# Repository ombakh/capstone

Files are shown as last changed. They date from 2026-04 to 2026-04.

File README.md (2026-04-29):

# Capstone

Browser-based robot control app with directional controls, backend command routing,
Pi telemetry, dual Pi camera streaming, backend-managed session recording, and
ESP32 serial ESC control.

Complete robot guide: [docs/complete-robot.md](./docs/complete-robot.md)
WebRTC video path: [docs/webrtc-video-first-pass.md](./docs/webrtc-video-first-pass.md)
ESP32 serial ESC control: [docs/esp32-serial-esc-control.md](./docs/esp32-serial-esc-control.md)

## Complete Robot Setup

The completed robot baseline in this repo is:

- PC: runs the backend and serves the web app
- Raspberry Pi 5: runs `pi/gateway.py` for controls, telemetry, LiDAR, and
  robot-side status
- WebRTC publisher: runs `pi/webrtc_publisher.py` for low-latency front/back
  camera video
- Web app: shows the two Pi camera feeds, renders LiDAR, exposes arm/disarm,
  and sends arrow-key drive commands
- ESP32: receives serial commands from the Pi and generates hardware-timed
  left/right ESC pulses with a neutral watchdog

Echo mode remains available for bench testing the command path before motors are
armed.

## Project Layout

- `backend/`: realtime gateway for Pi connections and UI commands
- `web/`: static frontend app (`index.html`, `styles.css`, `app.js`)
- `pi/`: Raspberry Pi gateway (`gateway.py`)
- `esp/`: ESP32 serial-controlled ESC firmware
- `docs/`: architecture and protocol notes
- `chasis/`: STL chassis model

## Technical Description: Complete Robot Stack

This section describes the robot stack this repository is built to run.

### Onboard Hardware

- Raspberry Pi 5:
  primary onboard computer that runs the edge gateway, owns the sensors, and
  connects back to the control backend over LAN or Tailscale.
- ESP32 motor controller:
  connected to the Pi over USB serial and responsible for hardware-timed
  left/right ESC signal pulses. The default ESP32 GPIO mapping is `GPIO18` for
  the left ESC and `GPIO19` for the right ESC.
- Two ESC signal leads:
  connected to the ESP32 signal outputs, with a shared signal ground between
  the Pi, ESP32, and ESCs. The checked-in PlatformIO config targets
  bidirectional ESCs with centered neutral.
- Two Raspberry Pi NOIR camera modules:
  attached to the Pi camera connectors and treated as the front and back robot
  cameras. The current default mapping is camera index `0` for the front feed and
  camera index `1` for the back feed.
- LiDAR sensor:
  connected over USB serial and streamed by the Pi as `lidar.scan` events for
  the frontend map view.

### Onboard Software

- `pi/gateway.py`:
  the main robot-side process. It connects to the backend as the robot device,
  publishes Pi temperature, camera status, live camera frames, and LiDAR data,
  and drives motors in one of three modes: terminal echo, ESP32 serial ESC
  control, or legacy direct Pi GPIO ESC control.
- Raspberry Pi camera stack:
  the preferred live-camera path uses `rpicam-vid` or `libcamera-vid`; OpenCV is
  only a fallback when those tools are unavailable.
- Python dependencies:
  the Pi gateway depends on `websockets`, `pyserial`, and
  `rplidar-roboticia`, with `python3-opencv` optional for the fallback camera
  path.
- Serial links:
  the Pi can maintain one USB serial path to the LiDAR and another to the ESP32,
  depending on whether the robot is in echo-only mode or using the ESP32 motor
  controller.

### Low-Level Control Status

- The primary robot control path is ESP32 serial ESC control:
  web UI -> backend -> Pi gateway -> ESP32 serial -> left/right ESC signal pulses.
- The web UI does not drive live motors immediately. It must receive
  `motor.status` from the Pi, you must arm the ESCs explicitly, and held arrow
  keys are refreshed from the browser while the ESP32 applies its watchdog
  timeout and neutral fallback.
- The legacy direct Pi ESC path still exists as `PI_MOTOR_DRIVER=esc`, but the
  preferred motor path is `PI_MOTOR_DRIVER=esp`.

### Off-Robot Infrastructure

- Backend server:
  runs on a separate PC and acts as the command broker, WebRTC signaling relay,
  recording coordinator, and realtime fan-out service for UI clients and the Pi.
- Web frontend:
  served from the PC, shows the robot camera feeds and LiDAR view, and
  sends drive commands to the robot. It can also start/stop backend-managed
  recording sessions, pause/resume them mid-run, and download the finished
  fixed-layout MP4 once rendering completes.
- Network dependency:
  the Pi must be able to reach the backend on port `3000`; the documented setup
  uses either the local network or Tailscale.

### Practical Summary

The robot is a Raspberry Pi 5 with two NOIR cameras, USB LiDAR, an ESP32 serial
ESC controller, two ESCs, and the chassis model in this repo. The normal
development topology keeps backend/web hosting on the PC; move that onto the Pi
only if the deployment plan changes.

## Requirements

PC:

- `node` and `npm` (`backend/package.json` requires Node `>=18`)
- `python3`
- `make`
- PlatformIO CLI (`pio`) for ESP32 firmware builds/uploads
- macOS Swift command-line toolchain when rendering recording MP4s

Pi:

- `python3`
- `make`
- a Python virtual environment is strongly recommended

## Quick Start: Echo Bench Test

### 1. Start the PC side

```bash
make pc-setup
make pc-start
```

That runs:

- backend on `0.0.0.0:3000`
- web app on `http://127.0.0.1:8080`

### 2. Prepare the Pi Python environment

From the repo root on the Pi:

```bash
python3 -m venv .venv
source .venv/bin/activate
make pi-setup
```

### 3. Connect the Pi to the PC backend

If both devices are on a network that allows peer-to-peer traffic:

```bash
make pi-connect-echo PC_IP=<pc-ip>
```

If you are on campus or guest Wi-Fi, use the PC's Tailscale IP instead of its
local Wi-Fi IP.

`make pi-connect-echo` now carries LiDAR scans over the same backend path by
default. The Makefile leaves the serial device unset unless you pass
`PI_LIDAR_PORT=/dev/ttyUSB1`, so `gateway.py` can apply its motor-driver-specific
default. Disable streaming with `PI_LIDAR_ENABLED=0`.

To isolate LiDAR hardware from the webapp path, stop the Pi gateway and run
this on the Pi:

```bash
make pi-serial-list
make pi-lidar-check
```

If the LiDAR is not on the default serial device, pass the detected port:

```bash
make pi-lidar-check PI_LIDAR_PORT=/dev/ttyUSB0
```

The Pi gateway also logs the detected serial devices and the selected `espPort`
and `lidarPort` at startup. If the ESP32 and LiDAR swap `/dev/ttyUSB*` numbers,
prefer passing the stable `/dev/serial/by-id/...` path shown by
`make pi-serial-list` as `ESP_SERIAL_PORT` or `PI_LIDAR_PORT`.

When LiDAR is enabled and only one USB serial device is detected, the gateway
reserves that device for LiDAR and leaves the ESP motor serial port unassigned
unless `ESP_SERIAL_PORT` is explicitly set. This keeps LiDAR scans working even
when the ESP32/motor controller is not plugged in.

The complete drive target uses those stable paths like this:

```bash
make pi-connect-webrtc-esp PC_IP=192.168.1.25 \
  ESP_SERIAL_PORT=/dev/serial/by-id/<esp32-device> \
  PI_LIDAR_PORT=/dev/serial/by-id/<lidar-device>
```

### 4. Use the web app

Open `http://127.0.0.1:8080` on the PC and press the arrow keys.

If two camera modules are attached to the Pi, the main view and side preview use
camera index `0` as the front feed and camera index `1` as the back feed. The
WebRTC targets publish both feeds over WebRTC; non-WebRTC Pi targets carry
camera frames over the backend WebSocket path.

To verify both camera indexes outside the webapp/WebRTC path, stop the Pi
service and run:

```bash
make pi-camera-check
```

The check captures each camera once, then runs a short simultaneous
WebRTC-style stream probe. If the still captures pass but the simultaneous
stream fails, check camera power/cables or lower the WebRTC resolution/FPS. If
the reported camera indexes are reversed or different, override them with
`WEBRTC_CAMERA_FRONT_INDEX` and `WEBRTC_CAMERA_BACK_INDEX` in the service.

Expected Pi output:

```text
Motor command [echo-only] id=... drive direction=forward speed=0.15 durationMs=3000
Motor command [echo-only] id=... stop
```

## Quick Start: Complete Robot Drive Mode

This is the normal live-driving mode for the complete robot. The Raspberry Pi
forwards commands over serial, the ESP32 generates ESC signal pulses, LiDAR
streams through the gateway, and both cameras publish over WebRTC.

### 1. Flash the ESP32 firmware

From the repo root on the PC:

```bash
pio run -d esp
pio run -d esp -t upload
```

The firmware emits `motor.status` JSON at `115200` baud.

### 2. Install the Pi Python dependencies

From the repo root on the Pi:

```bash
python3 -m venv .venv
source .venv/bin/activate
make pi-setup
```

`pyserial` is required for the Pi-to-ESP32 link.

### 3. Wire the ESC receiver leads to the ESP32

Default signal pins:

- Left ESC signal -> ESP32 GPIO `18`
- Right ESC signal -> ESP32 GPIO `19`
- ESC signal grounds -> ESP32 ground
- Pi ground -> ESP32 ground
- Pi USB -> ESP32 USB serial

Power rules:

- Do not power the motors from the Pi or ESP32.
- Power each ESC from the robot battery or motor power bus.
- The Pi, ESP32, and both ESCs must share signal ground.
- Do not tie multiple ESC BEC 5V outputs together.
- Do not backfeed ESC voltage into Pi or ESP32 GPIO.

### 4. Start ESP32 ESC mode and WebRTC video on the Pi

If the Pi is connecting to a PC-hosted backend:

```bash
make pi-connect-webrtc-esp PC_IP=<pc-ip>
```

When possible, pass stable serial paths from `make pi-serial-list`:

```bash
make pi-connect-webrtc-esp PC_IP=<pc-ip> \
  ESP_SERIAL_PORT=/dev/serial/by-id/<esp32-device> \
  PI_LIDAR_PORT=/dev/serial/by-id/<lidar-device>
```

### 5. Arm and drive from the web app

- Open the web app on the PC.
- Wait for the motor panel to show the ESP driver as available.
- Click `Arm Motors`.
- Wait for the panel to change from `ARMING` to `ARMED`.
- Use the arrow keys.

The ESP32 keeps both ESCs at neutral on startup, disarm, stop, and watchdog
timeout. While a key is held, the web app refreshes the `drive` command; if
those refreshes stop, the ESP32 returns both ESCs to neutral automatically.

## Recording Mode

Backend recording captures LiDAR scans and backend-carried JPEG camera frames.
The live WebRTC media path is peer-to-peer, so use the non-WebRTC Pi target when
you need the rendered MP4 to include both camera feeds:

```bash
make pi-connect-esp PC_IP=<pc-ip> \
  ESP_SERIAL_PORT=/dev/serial/by-id/<esp32-device> \
  PI_LIDAR_PORT=/dev/serial/by-id/<lidar-device>
```

Then open:

```text
http://127.0.0.1:8080?deviceId=pi-01&webrtc=0
```

Start, pause/resume, and stop recording from the web UI. The backend renders the
finished session into an MP4 using [backend/scripts/render_recording.swift](./backend/scripts/render_recording.swift).

## ESP32 ESC Wiring

The ESP32 ESC path assumes ESCs that accept standard RC servo-style control
pulses, not DShot-only ESCs.

Default wiring:

- Left ESC signal -> ESP32 GPIO `18`
- Right ESC signal -> ESP32 GPIO `19`
- ESC signal grounds -> ESP32 ground
- Pi ground -> ESP32 ground
- ESC main battery leads -> robot battery / motor power distribution
- Brushless motor phase wires -> ESC motor outputs

If your drivetrain is mounted so one side spins the opposite way for the same
throttle command, compile the firmware with `ESC_LEFT_INVERTED=1` or
`ESC_RIGHT_INVERTED=1`, or swap motor phase wires where appropriate.

The checked-in [esp/platformio.ini](./esp/platformio.ini) config is tuned for
the complete robot's bidirectional ESCs:

- `ESC_BIDIRECTIONAL=1`
- `ESC_ARM_PULSE_US=1500`
- `ESC_NEUTRAL_PULSE_US=1500`
- `ESC_FORWARD_MIN_PULSE_US=1560`
- `ESC_FORWARD_MAX_PULSE_US=1900`
- `ESC_REVERSE_MIN_PULSE_US=1440`
- `ESC_REVERSE_MAX_PULSE_US=1100`
- `ESC_MAX_SPEED=0.35f`

The ESP32 arms by holding `ESC_ARM_PULSE_US` for `ESC_ARM_DELAY_MS`, clamps
requested speed to `ESC_MAX_SPEED`, and returns both ESCs to neutral if command
refresh stops for `ESC_WATCHDOG_TIMEOUT_MS`.

Detailed setup: [docs/esp32-serial-esc-control.md](./docs/esp32-serial-esc-control.md)

## Network Notes

- The Pi must be able to reach the PC backend on port `3000`.
- Many campus, guest, and enterprise Wi-Fi networks block device-to-device traffic.
- If `curl http://<pc-ip>:3000/health` hangs from the Pi, use Tailscale or a different network.

## Useful Commands

- `make serve`: serve `web/` on `WEB_HOST:PORT`
- `make run`: run backend and web app together with default local settings
- `make check`: run `node --check` on `web/app.js`
- `make backend-install`: install backend dependencies
- `make backend-dev`: run backend in watch mode
- `make backend-start`: run backend without watch mode
- `make pc-setup`: install PC-side backend dependencies
- `make pc-backend`: run the backend on the PC
- `make pc-web`: serve the web app on the PC
- `make pc-start`: run backend and web app on the PC
- `make pi-install`: install Raspberry Pi gateway dependencies
- `make pi-setup`: install Raspberry Pi gateway dependencies
- `make pi-run`: run the Pi gateway with its default settings
- `make pi-run-echo`: run the Pi gateway in local echo-only mode
- `make pi-run-esp`: run the Pi gateway with ESP32 serial ESC control
- `make pi-run-esc`: run the legacy direct Pi GPIO ESC path
- `make pi-connect-echo PC_IP=<ip>`: connect the Pi echo gateway to the PC backend
- `make pi-connect-esp PC_IP=<ip>`: connect the Pi ESP32 ESC gateway to the PC backend
- `make pi-connect-esc PC_IP=<ip>`: connect the legacy direct Pi GPIO ESC gateway to the PC backend
- `make pi-connect-webrtc-echo PC_IP=<ip>`: connect echo controls and publish WebRTC video
- `make pi-connect-webrtc-esp PC_IP=<ip>`: connect ESP32 ESC controls and publish WebRTC video
- `make pi-connect-webrtc-esc PC_IP=<ip>`: connect legacy direct Pi GPIO ESC controls and publish WebRTC video
- `CAMERA_STREAM_HZ`, `CAMERA_FRAME_WIDTH`, `CAMERA_FRAME_HEIGHT`, `CAMERA_JPEG_QUALITY`: tune Pi camera streaming
- `WEBRTC_CAMERA_NAMES=front,back`, `WEBRTC_CAMERA_FRONT_INDEX`, `WEBRTC_CAMERA_BACK_INDEX`, `WEBRTC_CAMERA_WIDTH`, `WEBRTC_CAMERA_HEIGHT`, `WEBRTC_CAMERA_FPS`: tune WebRTC camera streaming
- `WEBRTC_CAMERA_FRONT_WIDTH`, `WEBRTC_CAMERA_FRONT_HEIGHT`, `WEBRTC_CAMERA_FRONT_FPS`, `WEBRTC_CAMERA_BACK_WIDTH`, `WEBRTC_CAMERA_BACK_HEIGHT`, `WEBRTC_CAMERA_BACK_FPS`: override per-camera WebRTC profiles
- `PI_LIDAR_PORT=/dev/ttyUSB1`: override the LiDAR serial port when the gateway default is wrong
- `PI_MOTOR_DRIVER=esp`, `ESP_SERIAL_PORT`, `ESP_BAUD`: use the ESP32 serial ESC path
- `ESC_*` firmware build flags in `esp/platformio.ini`: tune ESP32 ESC pulses
- `make pi-keys`: send direct arrow-key serial input to an attached ESP32
- `make help`: list available targets

## Additional Docs

- Complete robot guide: [docs/complete-robot.md](./docs/complete-robot.md)
- Pi gateway: [pi/README.md](./pi/README.md)
- ESP32 firmware: [esp/README.md](./esp/README.md)
- ESP32 ESC setup: [docs/esp32-serial-esc-control.md](./docs/esp32-serial-esc-control.md)
- WebRTC video path: [docs/webrtc-video-first-pass.md](./docs/webrtc-video-first-pass.md)
- Backend API and WebSocket protocol: [backend/README.md](./backend/README.md)
- End-to-end architecture: [docs/edge-system-base.md](./docs/edge-system-base.md)

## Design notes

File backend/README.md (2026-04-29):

# Backend Gateway

Realtime gateway between the complete robot's Raspberry Pi gateway, WebRTC
publisher, and web frontend.

This service is the command broker for the project:

- UI clients connect as `role=ui`
- Pi gateways connect as `role=pi`
- UI commands are validated, queued if needed, and forwarded to the target Pi
- Pi events and acknowledgements are broadcast back to connected UI clients
- WebRTC signaling is relayed between the browser viewer and Pi publisher
- The backend can record LiDAR scans and backend-carried camera frames into
  session folders and render the finished session as a downloadable MP4

## Run

From the repo root:

```bash
make backend-install
make backend-start
```

Or directly from `backend/`:

```bash
cd backend
npm install
npm run dev
```

Server defaults to `http://127.0.0.1:3000` locally and listens on `0.0.0.0`
when started through the root `Makefile`.

## Environment

- `BACKEND_HOST` default: `0.0.0.0`
- `BACKEND_PORT` default: `3000`
- `BACKEND_CORS_ORIGINS` default: `*`
- `PI_DEVICE_TOKEN` optional shared token for Pi auth
- `EVENT_HISTORY_LIMIT` default: `300`
- `COMMAND_QUEUE_LIMIT` default: `100`
- `BACKEND_RECORDINGS_DIR` default: `<backend cwd>/recordings`
- `RECORDINGS_HISTORY_LIMIT` default: `25`
- `RECORDING_VIDEO_WIDTH` default: `1280`
- `RECORDING_VIDEO_HEIGHT` default: `720`
- `RECORDING_VIDEO_FPS` default: `12`
- `RECORDING_RENDERER_SCRIPT` default: `<backend cwd>/scripts/render_recording.swift`

## Health Check

```bash
curl http://127.0.0.1:3000/health
```

Expected response shape:

```json
{
  "ok": true,
  "uptimeSeconds": 12,
  "connectedUiClients": 1,
  "connectedPiClients": 1,
  "connectedWebRtcPiClients": 1,
  "connectedWebRtcViewerClients": 1
}
```

When using a PC-hosted backend with a Pi on another device, verify that the Pi
can reach this endpoint before debugging the WebSocket path.

## HTTP API

- `GET /health`: liveness + connection counts
- `GET /api/state`: latest in-memory snapshot
- `POST /api/pi/event`: ingest Pi event payload
- `POST /api/ui/command`: send command to a Pi device
- `POST /api/ui/drive`: validated drive command helper endpoint
- `POST /api/recordings/start`: begin backend-managed recording for a Pi device
- `POST /api/recordings/pause`: pause or resume an active recording
- `POST /api/recordings/stop`: stop and render an active recording
- `GET /api/recordings/:recordingId/download`: download a finished recording MP4

### `POST /api/pi/event` payload

```json
{
  "deviceId": "pi-01",
  "eventType": "telemetry",
  "payload": {
    "battery": 89,
    "heading": 42
  }
}
```

### `POST /api/ui/command` payload

```json
{
  "deviceId": "pi-01",
  "command": "drive",
  "params": {
    "direction": "forward",
    "speed": 0.6
  }
}
```

### `POST /api/ui/drive` payload

```json
{
  "deviceId": "pi-01",
  "direction": "forward",
  "speed": 0.6,
  "durationMs": 0
}
```

### `POST /api/recordings/start` payload

```json
{
  "deviceId": "pi-01"
}
```

The backend stores:

- `lidar.ndjson`
- `camera-front.ndjson` / `camera-back.ndjson`
- JPEG frames under `cameras/front/` and `cameras/back/`
- `manifest.json`

When stopped, the backend renders the session into a fixed-layout `.mp4` with a
large LiDAR view and any camera feeds received on the backend WebSocket path.
The web UI keeps the download arrow hidden until that MP4 is ready.
The default renderer is the Swift script in `backend/scripts/`, so the host
running the backend must have the macOS command-line Swift toolchain available.

The low-latency WebRTC media path is peer-to-peer and is not recorded by the
backend. For MP4s with both camera feeds, run the Pi gateway JPEG camera path
and open the browser with `?webrtc=0`.

## WebSocket

Path: `/ws`

- UI connect: `/ws?role=ui`
- Pi connect: `/ws?role=pi&deviceId=pi-01&token=<PI_DEVICE_TOKEN>`

Message types:

- Pi -> backend: `pi:event`, `pi:ack`, `pi:heartbeat`
- Pi -> backend: `pi:camera_frame`
- UI -> backend: `ui:command`
- Backend -> UI: `snapshot`, `pi:event`, `pi:status`, `pi:ack`, `command:accepted`, `command:delivered`, `camera:frame`, `recording:status`, `pi:webrtc-status`
- Backend -> Pi: `ui:command`

WebRTC signaling path: `/webrtc`

- Pi publisher connect: `/webrtc?role=pi&deviceId=pi-01&token=<PI_DEVICE_TOKEN>`
- Browser viewer connect: `/webrtc?role=viewer&deviceId=pi-01`
- Signaling messages: `viewer:ready`, `viewer:profile`, `webrtc:offer`, `webrtc:answer`, `webrtc:ice`
- The backend relays only signaling. WebRTC video media flows peer-to-peer.

See [WebRTC Video Path](../docs/webrtc-video-first-pass.md) for the run flow.

## Common Development Topology

The complete robot development flow is:

- PC runs this backend on port `3000`
- PC serves the web app on port `8080`
- Pi runs `pi/gateway.py`
- Pi runs `pi/webrtc_publisher.py` for low-latency live video when using a
  WebRTC target
- Pi connects to the PC over LAN or Tailscale

If the Pi cannot reach the PC on campus Wi-Fi, use a Tailscale IP or another
network that allows peer-to-peer traffic.

See [Complete Robot Guide](../docs/complete-robot.md) for the full bring-up
sequence.

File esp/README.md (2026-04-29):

# ESP32 ESC Firmware

This PlatformIO project contains the ESP32 firmware for low-level motor signal
generation. The Raspberry Pi sends newline-delimited JSON commands over serial;
the ESP32 owns the ESC PWM outputs for the complete robot.

## What It Does

- Generates hardware-timed 50 Hz RC servo pulses with ESP32 LEDC.
- Drives two ESC signal outputs, defaulting to GPIO `18` left and GPIO `19` right.
- Holds neutral on boot, disarm, stop, and watchdog timeout.
- Requires `arm_motors` before drive commands are accepted.
- Ramps pulse widths toward targets to avoid abrupt throttle changes.
- Publishes `motor.status` JSON lines back to the Pi once per second and on state
  changes.

## Complete Robot Configuration

The firmware source has conservative forward-only compile defaults, but the
checked-in [platformio.ini](./platformio.ini) overrides them for the complete
robot's bidirectional ESCs:

| Setting | Current repo value |
| --- | --- |
| `ESC_BIDIRECTIONAL` | `1` |
| `ESC_ARM_PULSE_US` | `1500` |
| `ESC_NEUTRAL_PULSE_US` | `1500` |
| `ESC_FORWARD_MIN_PULSE_US` | `1560` |
| `ESC_FORWARD_MAX_PULSE_US` | `1900` |
| `ESC_REVERSE_MIN_PULSE_US` | `1440` |
| `ESC_REVERSE_MAX_PULSE_US` | `1100` |
| `ESC_MAX_SPEED` | `0.35f` |

Keep those values synchronized with the ESC calibration verified on the bench.
The checked-in upload and monitor port point at the development USB adapter;
override them from the command line or edit `platformio.ini` if your adapter
enumerates differently.

## Wiring

Default signal wiring:

- Left ESC signal -> ESP32 GPIO `18`
- Right ESC signal -> ESP32 GPIO `19`
- ESC signal grounds -> ESP32 ground
- Raspberry Pi ground -> ESP32 ground
- ESP32 USB -> Raspberry Pi USB for serial

Power each ESC from the robot battery or motor power bus. Do not power motors
from the ESP32 or Raspberry Pi, and do not backfeed ESC BEC outputs into either
board unless you have a deliberate power-distribution plan.

## Build And Upload

From the repo root:

```bash
pio run -d esp
pio run -d esp -t upload
```

Monitor the JSON status stream:

```bash
pio device monitor -d esp -b 115200
```

Bench-test directly from a Mac or Linux host connected to the ESP32:

```bash
python3 esp/serial_motor_test.py --list-ports
python3 esp/serial_motor_test.py --port /dev/cu.usbserial-XXXX
```

Controls:

- `a`: arm
- `d`: disarm
- arrow keys: drive
- space or `s`: stop
- `+` / `-`: adjust speed
- `m`: request status
- `q`: quit

Install `pyserial` first if needed:

```bash
pip install pyserial
```

## Serial Commands

The Pi gateway sends compact JSON lines like:

```json
{"type":"command","id":"123","command":"drive","params":{"direction":"forward","speed":0.15,"durationMs":3000}}
```

Supported commands:

- `motor_status`
- `arm_motors`
- `disarm_motors`
- `drive` with `direction`, `speed`, and `durationMs`
- `stop`

The firmware responds with `ack` lines for non-drive commands and drive errors,
and with `motor.status` lines for frontend safety state.

## Tuning

Compile defaults are defined in [src/main.cpp](./src/main.cpp). Override them
with PlatformIO build flags when needed:

```ini
build_flags =
  -D LEFT_ESC_PIN=18
  -D RIGHT_ESC_PIN=19
  -D ESC_MAX_SPEED=0.15f
  -D ESC_ARM_PULSE_US=1000
  -D ESC_NEUTRAL_PULSE_US=1000
  -D ESC_FORWARD_MIN_PULSE_US=1100
  -D ESC_FORWARD_MAX_PULSE_US=2000
```

For another bidirectional ESC calibration, start from the current repo flags and
adjust the pulse widths:

```ini
build_flags =
  -D ESC_BIDIRECTIONAL=1
  -D ESC_ARM_PULSE_US=1500
  -D ESC_NEUTRAL_PULSE_US=1500
  -D ESC_FORWARD_MIN_PULSE_US=1560
  -D ESC_FORWARD_MAX_PULSE_US=1900
  -D ESC_REVERSE_MIN_PULSE_US=1440
  -D ESC_REVERSE_MAX_PULSE_US=1100
  -D ESC_MAX_SPEED=0.35f
```

Use the lower speed cap until each ESC is calibrated and the drivetrain is
tested on a stand.

If one side of the drivetrain is mechanically mirrored, add
`ESC_LEFT_INVERTED=1` or `ESC_RIGHT_INVERTED=1` instead of changing the browser
direction mapping.

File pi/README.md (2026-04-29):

# Raspberry Pi Robot Gateway

`gateway.py` is the robot-side bridge between the PC backend, onboard sensors,
and the motor controller.

Responsibilities:

- Connect to backend WebSocket as a Pi device (`role=pi`).
- Print incoming drive commands in echo mode for bench testing.
- Forward drive/motor commands to an ESP32 over serial for ESC pulse generation.
- Keep the legacy direct Raspberry Pi GPIO ESC path available for fallback tests.
- Publish motor status, camera status, LiDAR status, temperature, and ESP telemetry.
- Stream live JPEG frames for both configured Pi cameras to the frontend.
- Stream live LiDAR scans (`lidar.scan`) to backend for web rendering.

The WebRTC video path runs as a separate Pi publisher process:
`pi/webrtc_publisher.py`. Use `PI_CAMERA_JPEG_ENABLED=0` on `gateway.py` when
the WebRTC publisher owns the camera. See
[WebRTC Video Path](../docs/webrtc-video-first-pass.md).

## Install

From the repo root on the Pi:

```bash
python3 -m venv .venv
source .venv/bin/activate
make pi-setup
```

The preferred camera path uses `rpicam-vid` or `libcamera-vid`, which are part
of the Raspberry Pi camera stack. OpenCV remains a fallback path when those
commands are unavailable.

Optional for the OpenCV fallback:

```bash
sudo apt-get install -y python3-opencv
```

The preferred motor path uses `pyserial` to talk to the ESP32.

Optional for the legacy direct Pi GPIO ESC fallback:

```bash
sudo apt-get install -y swig build-essential python3-dev liblgpio-dev
python3 -m pip install lgpio
```

## Run

With the virtual environment activated:

```bash
make pi-run
```

For no-hardware testing, run the gateway in terminal echo mode:

```bash
make pi-run-echo
```

For ESP32 serial ESC control:

```bash
make pi-run-esp
```

For legacy direct Raspberry Pi GPIO ESC control:

```bash
make pi-run-esc
```

To connect the Pi to a PC-hosted backend in echo mode:

```bash
make pi-connect-echo PC_IP=<pc-ip>
```

To connect in ESP32 ESC mode:

```bash
make pi-connect-esp PC_IP=<pc-ip>
```

To connect in legacy direct Pi GPIO ESC mode:

```bash
make pi-connect-esc PC_IP=<pc-ip>
```

If the local Wi-Fi blocks device-to-device traffic, use the PC's Tailscale IP.

With two camera modules attached, the web UI can show live Pi feeds through the
WebRTC publisher or through backend-carried JPEG frames, depending on the run
target. The default mapping is camera index `0` for the front feed and camera
index `1` for the back feed. The web settings menu can adjust the JPEG camera
FPS at runtime; WebRTC profiles are set with `WEBRTC_CAMERA_*` environment
variables.

## Complete Robot Run Profiles

Low-latency driving profile:

1. Start the backend and web app on the PC with `make pc-start`.
2. Flash the ESP32 firmware from `esp/`.
3. Wire ESC signal and ground leads to the ESP32, with Pi and ESP32 grounds common.
4. Activate the Pi virtual environment.
5. Run `make pi-serial-list` and prefer stable `/dev/serial/by-id/...` paths.
6. Run `make pi-connect-webrtc-esp PC_IP=<pc-ip-or-tailscale-ip>`.
7. Open the web app, wait for WebRTC, LiDAR, and motor status, click
   `Arm Motors`, then use the arrow keys.

Recording profile:

1. Start the backend and web app on the PC with `make pc-start`.
2. Activate the Pi virtual environment.
3. Run `make pi-connect-esp PC_IP=<pc-ip-or-tailscale-ip>`.
4. Open `http://127.0.0.1:8080?deviceId=pi-01&webrtc=0`.
5. Use the web recording controls to capture LiDAR plus backend-carried JPEG
   camera frames.

Echo bench profile:

1. Start the backend and web app on the PC with `make pc-start`.
2. Activate the Pi virtual environment.
3. Run `make pi-connect-echo PC_IP=<pc-ip-or-tailscale-ip>`.
4. Press the web app arrow keys on the PC.
5. Watch the Pi terminal print the received motor commands.

See the full operating sequence in
[Complete Robot Guide](../docs/complete-robot.md).

## ESP32 Serial ESC Control

This is the complete robot's primary motor path. It assumes ESCs that accept
standard RC servo-style control pulses. DShot-only ESCs are not compatible with
this firmware.

Default wiring:

- Pi USB -> ESP32 USB serial
- Pi ground -> ESP32 ground
- Left ESC signal -> ESP32 GPIO `18`
- Right ESC signal -> ESP32 GPIO `19`
- ESC grounds -> ESP32 ground

Browser, Pi, and ESP32 safety behavior:

1. The ESP32 boots with both ESC outputs held at neutral.
2. The ESP32 publishes `motor.status` JSON over serial.
3. The Pi republishes fresh ESP status to the backend as `motor.status`.
4. The browser keeps the arrow keys disabled until the ESP32 reports
   `readyForDrive=true`.
5. You must click `Arm Motors` in the web UI.
6. The ESP32 holds `ESC_ARM_PULSE_US` for `ESC_ARM_DELAY_MS`.
7. While a key is held, the browser refreshes the `drive` command.
8. If refreshes stop for longer than `ESC_WATCHDOG_TIMEOUT_MS`, the ESP32 forces
   both ESCs back to neutral.
9. If ESP status becomes stale, the Pi marks the motor driver unavailable and
   the browser disables drive.

Detailed setup: [ESP32 Serial ESC Control](../docs/esp32-serial-esc-control.md).

## Legacy Direct Pi ESC Control

This fallback mode assumes ESCs that accept standard RC servo-style control
pulses and uses Raspberry Pi GPIO timing through `lgpio`. The complete robot
uses the ESP32 serial path above; keep this path for comparison or emergency
fallback testing.

Default GPIO wiring:

- Left ESC signal -> `GPIO18` (physical pin `12`)
- Right ESC signal -> `GPIO19` (physical pin `35`)
- ESC grounds -> any Pi ground, for example physical pin `14`, `20`, or `39`

Power and safety rules:

- The Pi and both ESCs must share a common ground.
- Do not power the motors from the Pi.
- Power each ESC from the robot battery or motor power bus.
- Most ESC receiver leads expose `signal`, `5V/BEC`, and `ground`.
  Recommended: connect only `signal` and `ground` to the Pi unless you have a
  deliberate regulator and power-distribution plan.
- Do not tie multiple ESC BEC 5V outputs together.
- Do not feed 5V into a Pi GPIO pin.

Browser and Pi safety behavior:

1. The Pi boots with both ESC outputs held at neutral.
2. The browser requests `motor.status` and keeps the arrow keys disabled until
   the Pi reports the motor driver is ready.
3. You must click `Arm Motors` in the web UI.
4. The Pi holds `ESC_ARM_PULSE_US` for `ESC_ARM_DELAY_SEC`.
5. Only when the Pi reports `ARMED` do arrow keys become live.
6. While a key is held, the browser refreshes the `drive` command.
7. If refreshes stop for longer than `ESC_WATCHDOG_TIMEOUT_MS`, the Pi forces
   both ESCs back to neutral.

Default drive mapping:

- Up arrow: both motors forward
- Down arrow: both motors reverse when `ESC_BIDIRECTIONAL=1`
- Left arrow: spin left with bidirectional ESCs, or pivot left with forward-only ESCs
- Right arrow: spin right with bidirectional ESCs, or pivot right with forward-only ESCs

If your drivetrain is mirrored mechanically, use `ESC_LEFT_INVERTED=1` or
`ESC_RIGHT_INVERTED=1`.

Forward-only ESCs are the default. If you are using bidirectional car ESCs
instead, set at least:

```bash
PI_MOTOR_DRIVER=esc \
ESC_BIDIRECTIONAL=1 \
ESC_ARM_PULSE_US=1500 \
ESC_NEUTRAL_PULSE_US=1500 \
ESC_FORWARD_MIN_PULSE_US=1560 \
ESC_FORWARD_MAX_PULSE_US=1900 \
python3 pi/gateway.py
```

## Direct Arrow-Key Control (Pi -> ESP32)

Use this when you want to bench-test the ESP32 ESC firmware directly from the Pi
terminal without running the backend/web stack.

```bash
python3 arrow_serial_bridge.py --port /dev/ttyUSB0 --baud 115200
```

Controls:

- `a`: arm motors
- `d`: disarm motors
- Arrow keys: send watchdog-limited drive commands
- Space or `s`: stop
- `+` / `-`: adjust speed
- `m`: request ESP32 motor status
- `q`: quit bridge

The helper sends newline-delimited JSON commands to match the same serial
protocol used by `gateway.py`.

## Environment Variables

- `BACKEND_WS_BASE` default: `ws://127.0.0.1:3000`
- `PI_DEVICE_ID` default: `pi-01`
- `PI_DEVICE_TOKEN` default: empty
- `ESP_SERIAL_PORT` default: `/dev/ttyUSB0`
- `ESP_BAUD` default: `115200`
- `PI_MOTOR_DRIVER` default: `esp` unless `PI_MOTOR_ECHO_ONLY=1`, supported values: `echo`, `esp`, `esc`
- `PI_MOTOR_ECHO` default: `1` (log incoming motor commands to the Pi terminal)
- `PI_MOTOR_ECHO_ONLY` default: `0` (legacy compatibility shortcut for `PI_MOTOR_DRIVER=echo`)

Legacy direct Pi GPIO ESC variables:

- `ESC_LEFT_GPIO` default: `18`
- `ESC_RIGHT_GPIO` default: `19`
- `ESC_GPIOCHIP` default: `-1` (auto-try `gpiochip4`, then `gpiochip0`)
- `ESC_LEFT_INVERTED` / `ESC_RIGHT_INVERTED` default: `0`
- `ESC_BIDIRECTIONAL` default: `0`
- `ESC_ARM_PULSE_US` default: `1000`
- `ESC_NEUTRAL_PULSE_US` default: `1000`
- `ESC_FORWARD_MIN_PULSE_US` default: `1100`
- `ESC_FORWARD_MAX_PULSE_US` default: `2000`
- `ESC_REVERSE_MIN_PULSE_US` default: `1440`
- `ESC_REVERSE_MAX_PULSE_US` default: `1100`
- `ESC_ARM_DELAY_SEC` default: `3.0`
- `ESC_WATCHDOG_TIMEOUT_MS` default: `3000`
- `ESC_MAX_SPEED` default: `0.15`
- `ESC_RAMP_STEP_US` default: `8`
- `ESC_UPDATE_HZ` default: `50`
- `ESC_SERVO_FREQUENCY_HZ` default: `50`
- `ESC_PULSE_REFRESH_MS` default: `0` (disabled; `tx_servo` pulses continue until changed)
- `CAMERA_FRONT_INDEX` default: `0`
- `CAMERA_BACK_INDEX` default: `1`
- `CAMERA_LEFT_INDEX` / `CAMERA_RIGHT_INDEX`: legacy fallback env vars still accepted
- `PI_HEARTBEAT_SEC` default: `5`
- `CAMERA_PUBLISH_SEC` default: `2`
- `CAMERA_STREAM_HZ` default: `6`
- `CAMERA_FRAME_WIDTH` default: `960`
- `CAMERA_FRAME_HEIGHT` default: `720`
- `CAMERA_JPEG_QUALITY` default: `60`
- `PI_CAMERA_JPEG_ENABLED` default: `1` (set `0` when `pi/webrtc_publisher.py` owns the camera)
- `WEBRTC_CAMERA_FRONT_INDEX` default: `WEBRTC_CAMERA_INDEX` / `CAMERA_FRONT_INDEX` / `0`
- `WEBRTC_CAMERA_BACK_INDEX` default: `CAMERA_BACK_INDEX` / `1`
- `WEBRTC_CAMERA_NAMES` default: `front,back` (set `front` to publish only the front WebRTC track)
- `WEBRTC_CAMERA_BACKEND` default: `auto`, supported values: `auto`, `rpicam`, `opencv`
- `WEBRTC_CAMERA_WIDTH` / `WEBRTC_CAMERA_HEIGHT` default to `640` / `480`
- `WEBRTC_CAMERA_FPS` default: `20`
- `WEBRTC_CAMERA_FRONT_WIDTH` / `WEBRTC_CAMERA_FRONT_HEIGHT` / `WEBRTC_CAMERA_FRONT_FPS`: override the front WebRTC camera profile
- `WEBRTC_CAMERA_BACK_WIDTH` / `WEBRTC_CAMERA_BACK_HEIGHT` / `WEBRTC_CAMERA_BACK_FPS`: override the back WebRTC camera profile, defaulting to at most `512x384@12fps`
- `WEBRTC_VIDEO_CODEC` default: `H264` (prefers H.264 in WebRTC negotiation)
- `WEBRTC_STATS_INTERVAL_SEC` default: `2`
- `WEBRTC_LOG_SDP` default: `1`
- `LIDAR_ENABLED` default: `1` (set `0` to disable streaming)
- `LIDAR_SERIAL_PORT` / `PI_LIDAR_PORT`: override the LiDAR serial port. Without an override the gateway prioritizes LiDAR when only one USB serial device is detected, then tries to choose a detected serial device that is not the ESP32 port, falling back to `/dev/ttyUSB1` when `PI_MOTOR_DRIVER=esp`, otherwise `/dev/ttyUSB0`.
- `LIDAR_MAX_DISTANCE_MM` default: `6000`
- `LIDAR_MIN_DISTANCE_MM` default: `120`
- `LIDAR_MAX_POINTS` default: `300`
- `LIDAR_PUBLISH_HZ` default: `10`
- `PI_RECONNECT_MAX_SEC` default: `20`

## Command Flow

Echo mode:

- Web UI sends command to backend (`/api/ui/command` or `/api/ui/drive`).
- Backend forwards command to this gateway as `ui:command`.
- Gateway prints the command in the Pi terminal and acknowledges it.

ESP serial mode:

- Web UI requests `motor_status`, then sends `arm_motors`, `drive`, and `stop`.
- Gateway writes command JSON to ESP32 over serial.
- ESP32 generates servo-style pulses on its configured GPIO pins.
- ESP32 keeps the ESCs at neutral while disarmed and during the arm delay.
- Gateway republishes fresh ESP32 `motor.status` as backend `motor.status`.
- The web UI only enables the arrow keys after the ESP32 reports `readyForDrive=true`.
- If command refresh stops, the ESP32 watchdog returns both ESCs to neutral.

Legacy direct ESC mode:

- Web UI requests `motor_status`, then sends `arm_motors`, `drive`, and `stop`.
- Gateway uses `lgpio` to output servo-style pulses on the configured GPIO pins.
- The Pi keeps the ESCs at neutral while disarmed and during the arm delay.
- If command refresh stops, the Pi watchdog returns both ESCs to neutral.

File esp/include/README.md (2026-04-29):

# include

No custom headers are required for the complete robot firmware at the moment.
Keep shared ESP32 declarations here if the firmware grows beyond
`../src/main.cpp`.

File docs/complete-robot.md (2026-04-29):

# Complete Robot Guide

This is the operating guide for the complete robot described by this repository.
The completed baseline uses a PC for the control station, a Raspberry Pi 5 on
the robot for networking and sensors, and an ESP32 as the timing-critical ESC
signal controller.

## System Topology

```text
Browser UI
  ^  WebRTC media from the Pi after signaling
  |  HTTP + WebSocket controls, telemetry, recording controls
  |  WebRTC signaling
  v
PC backend
  |  /ws command and event channel
  |  /webrtc signaling relay
  v
Raspberry Pi 5
  |  USB serial commands
  v
ESP32
  |  left/right RC-style ESC pulses
  v
Drive ESCs and motors
```

The Pi also owns both Pi cameras, the USB LiDAR, temperature telemetry, and the
robot-side connection back to the backend. The backend and web app run off-robot
in the normal development topology.

## Hardware Inventory

- Raspberry Pi 5 with a regulated 5V supply.
- ESP32 connected to the Pi over USB serial.
- Two bidirectional ESCs that accept standard RC servo-style pulse input.
- Two drive motors powered from the robot battery or motor power bus.
- Two Raspberry Pi NOIR cameras, mapped as `front` index `0` and `back` index
  `1` by default.
- USB LiDAR connected to the Pi.
- Common signal ground between the Pi, ESP32, and both ESC receiver leads.
- Chassis model under [chasis/ProjectBasicFinal.stl](../chasis/ProjectBasicFinal.stl).

Do not power the motors from the Pi or ESP32. Do not backfeed ESC BEC voltage
into either board unless the power-distribution design intentionally supports it.

## Software Roles

- [backend/src/server.js](../backend/src/server.js): command broker, event fan-out,
  WebRTC signaling relay, and recording renderer coordinator.
- [web/app.js](../web/app.js): browser UI for camera feeds, LiDAR map, motor
  arming, arrow-key driving, camera settings, and recording controls.
- [pi/gateway.py](../pi/gateway.py): robot-side gateway for commands, motor
  status, telemetry, LiDAR, and optional backend-carried JPEG camera frames.
- [pi/webrtc_publisher.py](../pi/webrtc_publisher.py): Pi-side WebRTC camera
  publisher for low-latency front/back live video.
- [esp/src/main.cpp](../esp/src/main.cpp): ESP32 firmware that generates
  hardware-timed ESC pulses and enforces the motor watchdog.

## Normal Drive Profile

Use this profile for the full robot with low-latency video:

1. Start the PC backend and web server.

   ```bash
   make pc-setup
   make pc-start
   ```

2. Flash the ESP32 firmware if it has changed.

   ```bash
   pio run -d esp
   pio run -d esp -t upload
   ```

3. On the Pi, create and activate the Python environment once.

   ```bash
   python3 -m venv .venv
   source .venv/bin/activate
   make pi-setup
   ```

4. List stable serial device names on the Pi.

   ```bash
   make pi-serial-list
   ```

5. Start the Pi gateway and WebRTC publisher together.

   ```bash
   make pi-connect-webrtc-esp PC_IP=<pc-ip-or-tailscale-ip> \
     ESP_SERIAL_PORT=/dev/serial/by-id/<esp32-device> \
     PI_LIDAR_PORT=/dev/serial/by-id/<lidar-device>
   ```

6. Open the browser UI on the PC.

   ```text
   http://127.0.0.1:8080?deviceId=pi-01
   ```

7. Wait for the Pi, WebRTC, LiDAR, and motor panels to report live status. Click
   `Arm Motors`, wait for `ARMED`, then use the arrow keys.

## Recording Profile

The backend MP4 recorder captures LiDAR scans plus camera frames that arrive as
`pi:camera_frame` messages on the backend WebSocket. The low-latency WebRTC
media path is peer-to-peer and is not ingested by the recorder.

Use this profile when the finished MP4 needs both camera feeds:

1. Start the PC backend and web server with `make pc-start`.
2. Start the Pi gateway without the WebRTC publisher so `gateway.py` owns the
   camera JPEG streams.

   ```bash
   make pi-connect-esp PC_IP=<pc-ip-or-tailscale-ip> \
     ESP_SERIAL_PORT=/dev/serial/by-id/<esp32-device> \
     PI_LIDAR_PORT=/dev/serial/by-id/<lidar-device>
   ```

3. Open the browser with WebRTC disabled.

   ```text
   http://127.0.0.1:8080?deviceId=pi-01&webrtc=0
   ```

4. Use the recording controls in the web UI. The backend writes a session folder
   and renders a fixed-layout MP4 when recording stops.

The renderer uses Swift, so the PC running the backend needs the macOS
command-line Swift toolchain when MP4 export is required.

## Motor Safety Contract

- The ESP32 holds both ESC outputs at neutral on boot, disarm, stop, and
  watchdog timeout.
- The browser disables driving until fresh `motor.status` reports the ESP32
  driver is available and `readyForDrive=true`.
- The user must explicitly arm motors from the UI before driving.
- Held arrow keys are refreshed by the browser; stale commands time out on the
  ESP32 after `ESC_WATCHDOG_TIMEOUT_MS`.
- The Pi marks the motor driver unavailable if ESP32 status becomes stale.

The repository PlatformIO config targets bidirectional ESCs with a centered
neutral: `ESC_BIDIRECTIONAL=1`, `ESC_ARM_PULSE_US=1500`,
`ESC_NEUTRAL_PULSE_US=1500`, and `ESC_MAX_SPEED=0.35f`.

## Bring-Up Checklist

1. Put the robot on a stand with wheels clear of the ground.
2. Confirm the PC backend is reachable from the Pi:

   ```bash
   make pi-backend-check PC_IP=<pc-ip-or-tailscale-ip>
   ```

3. Confirm serial devices:

   ```bash
   make pi-serial-list
   make pi-lidar-check PI_LIDAR_PORT=/dev/serial/by-id/<lidar-device>
   ```

4. Confirm cameras:

   ```bash
   make pi-camera-check
   ```

5. Run echo mode before enabling motors:

   ```bash
   make pi-connect-echo PC_IP=<pc-ip-or-tailscale-ip>
   ```

6. Run the complete WebRTC + ESP32 profile.
7. Arm motors and test one direction at low speed.
8. If one side spins backward, use `ESC_LEFT_INVERTED=1`,
   `ESC_RIGHT_INVERTED=1`, or swap motor phase wires as appropriate.
9. Confirm release-to-stop, browser focus loss, and disarm all return the
   drivetrain to neutral.

## Troubleshooting

- Pi cannot reach backend: campus or guest Wi-Fi may block peer-to-peer traffic;
  use Tailscale or another network.
- ESP32 and LiDAR swap `/dev/ttyUSB*` names: pass stable
  `/dev/serial/by-id/...` paths to `ESP_SERIAL_PORT` and `PI_LIDAR_PORT`.
- Motor panel never becomes ready: check ESP32 firmware, serial port, baud rate,
  common ground, and fresh `motor.status` lines in the Pi logs.
- Cameras fail under WebRTC: run `make pi-camera-check`, lower
  `WEBRTC_CAMERA_WIDTH` / `WEBRTC_CAMERA_HEIGHT` / `WEBRTC_CAMERA_FPS`, or use
  the OpenCV fallback.
- Recording has LiDAR but no camera frames: run the recording profile with
  `?webrtc=0`; WebRTC media is not recorded by the backend.
- Robot drives in the wrong direction: keep camera selection unchanged and fix
  drivetrain inversion in ESP32 build flags or wiring.

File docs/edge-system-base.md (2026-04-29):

# Edge System Base

## Roles

- **Web app**: sends drive commands, shows front/back video, renders LiDAR, shows
  motor state, and controls recording.
- **Backend**: command/event broker, realtime fan-out, WebRTC signaling relay,
  and backend-managed recording coordinator.
- **Raspberry Pi gateway**: connects to backend, owns LiDAR and telemetry, can
  publish backend-carried JPEG camera frames, and runs motors in `echo`,
  preferred `esp` serial mode, or legacy direct `esc` mode.
- **WebRTC publisher**: optional Pi process for low-latency front/back live
  camera video.
- **ESP32**: serial motor companion that generates hardware-timed ESC pulses and
  reports motor safety state.

## Common Development Topology

Complete robot setup:

- PC runs the backend and serves the web app
- Raspberry Pi runs `pi/gateway.py`
- Raspberry Pi runs `pi/webrtc_publisher.py` for the normal low-latency drive
  profile
- ESP32 connects to the Pi over USB serial and drives the ESC signal leads
- Pi connects to the PC backend over LAN or Tailscale
- Web app arrow keys become `drive` / `stop` commands on the Pi

If the Wi-Fi network blocks device-to-device traffic, the Pi will fail to reach
the PC backend directly. In that case, use Tailscale or a different network.

## Primary Flows

### 1) Drive command

1. Web app -> backend: `POST /api/ui/drive` or WebSocket `ui:command`
2. Backend -> Pi gateway: `ui:command`
3. Web app requests `motor.status`; in ESP mode the UI keeps arrow keys disabled until fresh ESP32 status reports `readyForDrive=true`
4. In ESP mode the user sends `arm_motors`; the Pi forwards it to the ESP32
5. Pi gateway -> terminal echo output, ESP32 serial JSON command line, or legacy direct ESC pulse updates
6. ESP32 -> Pi gateway: serial JSON ack/status
7. Pi gateway -> backend: `pi:event` (`motor.status`, `esp.*`, sensor events) and `pi:ack`
8. Backend -> Web app: realtime updates over WebSocket

### 2) Camera + sensor reporting

1. Pi probes camera status for both camera indexes.
2. Pi streams LiDAR scans as `lidar.scan`.
3. In WebRTC mode, `pi/webrtc_publisher.py` sends live camera media directly to
   browser peer connections after backend signaling.
4. In JPEG mode, `pi/gateway.py` sends `pi:camera_frame` messages through the
   backend WebSocket.
5. Pi sends `camera.status`, `motor.status`, and other status events to backend.
6. Backend forwards status and cached JPEG frames to UI subscribers.

### 3) No-hardware echo test

1. Web app sends arrow-key command.
2. Backend forwards `ui:command` to the Pi.
3. Pi gateway logs the command locally in `PI_MOTOR_DRIVER=echo` mode.
4. Pi gateway sends `pi:ack` back to the backend.
5. Backend can fan that acknowledgement out to UI clients.

### 4) ESC watchdog behavior

1. While an arrow key is held, the web app refreshes `drive` commands at a short interval.
2. In ESP mode, the ESP32 clamps requested speed to its firmware `ESC_MAX_SPEED`.
3. If command refresh stops for longer than `ESC_WATCHDOG_TIMEOUT_MS`, the ESP32 forces both ESCs back to neutral.
4. If ESP32 motor status becomes stale, the Pi marks the motor driver unavailable.

### 5) Recording

1. Web app starts a recording through `POST /api/recordings/start`.
2. Backend records `lidar.scan` events and any `pi:camera_frame` JPEG frames.
3. Pause/resume updates the backend session timeline.
4. Stop marks the session finalizing and invokes the Swift renderer.
5. Backend exposes the finished MP4 through `/api/recordings/:recordingId/download`.

WebRTC media is peer-to-peer and does not enter this recording path. Use the
non-WebRTC Pi target and open the UI with `?webrtc=0` when the MP4 must include
both camera feeds.

## Message Envelope (Backend Event)

```json
{
  "type": "pi:event",
  "event": {
    "deviceId": "pi-01",
    "eventType": "esp.telemetry",
    "timestamp": "2026-02-25T21:00:00.000Z",
    "payload": {},
    "metadata": {}
  }
}
```

## Device IDs

- Use one Pi gateway ID per robot, e.g. `pi-01`.
- If multiple ESP32s per Pi are added later, keep one Pi deviceId and include `espId` inside event payload.

For the full operating checklist, see [Complete Robot Guide](./complete-robot.md).

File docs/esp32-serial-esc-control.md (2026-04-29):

# ESP32 Serial ESC Control

This is the primary ESC path for the complete robot:

`web app -> backend -> pi/gateway.py -> USB serial -> ESP32 -> left/right ESC signal pulses`

The Pi still owns networking, cameras, LiDAR, and backend communication. The
ESP32 owns the timing-sensitive ESC signal generation.

## Hardware Wiring

Default signal wiring:

| Connection | Default |
| --- | --- |
| Pi USB | ESP32 USB serial |
| Pi ground | ESP32 ground |
| Left ESC signal | ESP32 GPIO `18` |
| Right ESC signal | ESP32 GPIO `19` |
| ESC grounds | ESP32 ground |
| ESC power leads | robot battery / motor power bus |

Power rules:

- Keep wheels or props off the ground while testing.
- The Pi, ESP32, and ESC signal grounds must be common.
- Do not power motors from the Pi or ESP32.
- Do not tie multiple ESC BEC 5V outputs together.
- Do not backfeed ESC voltage into Pi or ESP32 GPIO.

## Flash The ESP32

From the repo root:

```bash
pio run -d esp
pio run -d esp -t upload
```

Open the monitor to confirm that `motor.status` JSON is emitted:

```bash
pio device monitor -d esp -b 115200
```

## Start The Pi Gateway

The Pi gateway defaults to `PI_MOTOR_DRIVER=esp` unless echo-only mode is
enabled. Use the explicit target when connecting to a PC-hosted backend:

```bash
make pi-connect-esp PC_IP=<pc-ip-or-tailscale-ip>
```

With WebRTC video:

```bash
make pi-connect-webrtc-esp PC_IP=<pc-ip-or-tailscale-ip>
```

Without Make:

```bash
BACKEND_WS_BASE=ws://<pc-ip>:3000 PI_MOTOR_DRIVER=esp python3 pi/gateway.py
```

The ESP32 serial port defaults to `/dev/ttyUSB0`. Override it when needed:

```bash
ESP_SERIAL_PORT=/dev/ttyACM0 make pi-connect-esp PC_IP=<pc-ip>
```

On the complete robot, prefer stable serial paths from `make pi-serial-list`:

```bash
make pi-connect-webrtc-esp PC_IP=<pc-ip> \
  ESP_SERIAL_PORT=/dev/serial/by-id/<esp32-device> \
  PI_LIDAR_PORT=/dev/serial/by-id/<lidar-device>
```

When `PI_MOTOR_DRIVER=esp`, the gateway tries to keep the LiDAR and ESP32 on
separate serial devices. If only one USB serial device is detected and LiDAR is
enabled, the gateway reserves that device for LiDAR unless `ESP_SERIAL_PORT` is
explicitly set.

## Safety Contract

1. The ESP32 boots with both ESC outputs at neutral.
2. The ESP32 publishes `motor.status` over serial.
3. The Pi republishes fresh ESP status as backend `motor.status`.
4. The web UI keeps drive disabled until `driverAvailable=true` and
   `readyForDrive=true`.
5. `arm_motors` is forwarded to the ESP32.
6. The ESP32 holds the arm pulse for `ESC_ARM_DELAY_MS`.
7. Only after arming does the ESP32 accept `drive` commands.
8. Browser-held arrow keys refresh `drive` commands with a duration.
9. If refreshes stop or ESP status becomes stale, the drive path returns to
   neutral and the UI disables controls.

## Direct Serial Bench Test

After flashing the ESP32, you can test without the backend:

```bash
python3 pi/arrow_serial_bridge.py --port /dev/ttyUSB0 --baud 115200
```

Controls:

- `a`: arm
- `d`: disarm
- arrow keys: drive
- space or `s`: stop
- `+` / `-`: adjust speed
- `m`: request status
- `q`: quit

Each arrow key press sends a `drive` command with a short `durationMs`; the ESP32
watchdog returns to neutral when key-repeat stops.

## Firmware Configuration

Compile defaults live in [esp/src/main.cpp](../esp/src/main.cpp):

| Setting | Default |
| --- | --- |
| `LEFT_ESC_PIN` | `18` |
| `RIGHT_ESC_PIN` | `19` |
| `ESC_BIDIRECTIONAL` | `0` |
| `ESC_ARM_PULSE_US` | `1000` |
| `ESC_NEUTRAL_PULSE_US` | `1000` |
| `ESC_FORWARD_MIN_PULSE_US` | `1100` |
| `ESC_FORWARD_MAX_PULSE_US` | `2000` |
| `ESC_ARM_DELAY_MS` | `3000` |
| `ESC_WATCHDOG_TIMEOUT_MS` | `3000` |
| `ESC_MAX_SPEED` | `0.15f` |
| `ESC_RAMP_STEP_US` | `8` |
| `ESC_UPDATE_HZ` | `50` |

The checked-in [esp/platformio.ini](../esp/platformio.ini) overrides those
defaults for the complete robot's bidirectional ESCs:

| Setting | Current repo value |
| --- | --- |
| `ESC_BIDIRECTIONAL` | `1` |
| `ESC_ARM_PULSE_US` | `1500` |
| `ESC_NEUTRAL_PULSE_US` | `1500` |
| `ESC_FORWARD_MIN_PULSE_US` | `1560` |
| `ESC_FORWARD_MAX_PULSE_US` | `1900` |
| `ESC_REVERSE_MIN_PULSE_US` | `1440` |
| `ESC_REVERSE_MAX_PULSE_US` | `1100` |
| `ESC_MAX_SPEED` | `0.35f` |

Override firmware settings with PlatformIO `build_flags` if your wiring or ESC
calibration differs. For another bidirectional setup, start with
neutral-centered values:

```ini
build_flags =
  -D ESC_BIDIRECTIONAL=1
  -D ESC_ARM_PULSE_US=1500
  -D ESC_NEUTRAL_PULSE_US=1500
  -D ESC_FORWARD_MIN_PULSE_US=1560
  -D ESC_FORWARD_MAX_PULSE_US=1900
  -D ESC_REVERSE_MIN_PULSE_US=1440
  -D ESC_REVERSE_MAX_PULSE_US=1100
```

If one side of the drivetrain is mechanically mirrored, use
`ESC_LEFT_INVERTED=1` or `ESC_RIGHT_INVERTED=1` rather than changing the browser
or backend direction mapping.

## Legacy Pi GPIO ESC Mode

The legacy direct Pi GPIO path is still available as `PI_MOTOR_DRIVER=esc` and
`make pi-connect-esc`, but it is no longer the recommended setup for this robot.
Use it only for comparison or fallback testing.

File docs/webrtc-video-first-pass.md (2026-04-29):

# WebRTC Video Path

This is the low-latency live video path for the complete robot. It keeps
control, telemetry, LiDAR, and recording controls on the backend `/ws` socket,
and uses a separate WebRTC signaling socket at `/webrtc` for front/back camera
media. The file name still says `first-pass` for link compatibility.

## Architecture Overview

```text
Browser
  web/app.js
  - /ws?role=ui                         existing controls, telemetry, LiDAR
  - /webrtc?role=viewer&deviceId=pi-01  WebRTC signaling only
  - RTCPeerConnection                   receives the configured live video track(s)

PC backend
  backend/src/server.js
  - /ws                                 existing app protocol
  - /webrtc                             WebSocket signaling relay
  - no video media passes through this server

Raspberry Pi
  pi/gateway.py
  - existing controls, motor status, LiDAR, temperature
  - run with PI_CAMERA_JPEG_ENABLED=0 for the WebRTC path

  pi/webrtc_publisher.py
  - connects to /webrtc as role=pi
  - creates one RTCPeerConnection per browser viewer
  - publishes configured latest-frame-only camera tracks from pi/webrtc_camera.py
```

The negotiation flow is:

1. Browser opens `/webrtc?role=viewer&deviceId=pi-01`.
2. Pi publisher opens `/webrtc?role=pi&deviceId=pi-01`.
3. Browser sends `viewer:ready` with the requested output profiles.
4. Pi creates an offer with the configured video tracks and sends `webrtc:offer`.
5. Browser creates an answer and sends `webrtc:answer`.
6. Browser and Pi log SDP, ICE candidates, ICE state, signaling state, peer
   connection state, capture timing, outbound stats, and browser receive/render
   timing.

## Dependency List

PC backend:

- Node `>=18`
- Existing backend packages: `express`, `cors`, `dotenv`, `ws`

Browser:

- A browser with native WebRTC support
- No new frontend package dependency

Raspberry Pi:

- Existing Pi packages from `pi/requirements.txt`
- `aiortc>=1.14.0`
- `Pillow>=10.0.0`
- Preferred camera command: `rpicam-vid` or `libcamera-vid`
- Optional fallback camera package: `python3-opencv`

## File Structure

```text
backend/src/server.js       existing backend plus /webrtc signaling relay
web/index.html              main video element for WebRTC playback
web/app.js                  browser WebRTC signaling and peer connection code
pi/gateway.py               existing Pi gateway plus PI_CAMERA_JPEG_ENABLED
pi/webrtc_camera.py         rpicam/libcamera and OpenCV aiortc video tracks
pi/webrtc_publisher.py      Pi-side WebRTC publisher
pi/requirements.txt         Pi Python dependencies
Makefile                    run targets for the WebRTC path
```

## Run Steps

### 1. Start the PC backend and web app

From the repo root on the PC:

```bash
make pc-setup
make pc-start
```

This starts:

- backend: `http://0.0.0.0:3000`
- web app: `http://127.0.0.1:8080`

### 2. Prepare the Pi environment

From the repo root on the Pi:

```bash
python3 -m venv .venv
source .venv/bin/activate
make pi-setup
```

If the Pi does not have `rpicam-vid` or `libcamera-vid`, install the OpenCV
fallback:

```bash
sudo apt-get install -y python3-opencv
```

### 3. Run controls plus WebRTC video from the Pi

Echo/no-hardware controls:

```bash
make pi-connect-webrtc-echo PC_IP=<pc-ip-or-tailscale-ip>
```

ESP32 serial ESC controls:

```bash
make pi-connect-webrtc-esp PC_IP=<pc-ip-or-tailscale-ip>
```

Those targets start the complete live-driving Pi profile with two Pi processes:

- `pi/gateway.py` for the existing controls and telemetry path
- `pi/webrtc_publisher.py` for the WebRTC video path

They also set `PI_CAMERA_JPEG_ENABLED=0` so the gateway JPEG frame sender does
not open the camera at the same time as the WebRTC publisher.

The default WebRTC publisher starts both configured camera tracks. Set
`WEBRTC_CAMERA_NAMES=front` only when you intentionally want to test or run one
camera.

LiDAR still runs through `pi/gateway.py`. The Makefile no longer forces a LiDAR
serial port by default; pass `PI_LIDAR_PORT=/dev/serial/by-id/<lidar-device>`
when the gateway startup log shows it is probing the wrong device.

### 4. Open the browser

On the PC:

```text
http://127.0.0.1:8080?deviceId=pi-01
```

From another machine on the same network:

```text
http://<pc-ip>:8080?backendHost=<pc-ip>&deviceId=pi-01
```

### 5. Useful WebRTC knobs

```bash
WEBRTC_CAMERA_FRONT_INDEX=0
WEBRTC_CAMERA_BACK_INDEX=1
WEBRTC_CAMERA_NAMES=front,back # use front to publish one track
WEBRTC_CAMERA_BACKEND=auto     # auto | rpicam | opencv
WEBRTC_CAMERA_WIDTH=640
WEBRTC_CAMERA_HEIGHT=480
WEBRTC_CAMERA_FPS=20
WEBRTC_CAMERA_JPEG_QUALITY=70
WEBRTC_CAMERA_FRONT_WIDTH=640
WEBRTC_CAMERA_FRONT_HEIGHT=480
WEBRTC_CAMERA_FRONT_FPS=20
WEBRTC_CAMERA_BACK_WIDTH=512
WEBRTC_CAMERA_BACK_HEIGHT=384
WEBRTC_CAMERA_BACK_FPS=12
WEBRTC_VIDEO_CODEC=H264        # H264 preferred, VP8 fallback if unavailable
WEBRTC_STATS_INTERVAL_SEC=2
WEBRTC_LOG_SDP=1
```

When both WebRTC cameras are enabled, the browser sends per-camera output profile
requests. In camera view, the primary camera requests `640x480@20fps` and the
secondary camera requests `512x384@12fps`. The profile swaps when the camera
flip button is clicked by sending `viewer:profile`; the Pi keeps the WebRTC peer
and camera capture sources alive, then downscales or frame-skips only the lower
priority output track. In LiDAR view, both outputs request `512x384@12fps`.

The capture source profile is still set by the Pi environment. To get true
`640x480` detail after a flip, the capture source for that camera must also be
running at `640x480` or higher; otherwise the output can only upscale the lower
resolution source.

For a sharper but still conservative profile, try:

```bash
WEBRTC_CAMERA_WIDTH=1280 WEBRTC_CAMERA_HEIGHT=720 WEBRTC_CAMERA_FPS=15
```

Browser query-string overrides:

```text
?webrtc=0                     disables the WebRTC client path
?webrtcWs=<url-encoded-signaling-url>
```

## Logging

Backend logs use the `[webrtc]` prefix and include:

- signaling connects and disconnects
- SDP offer/answer type and full SDP body
- ICE candidate summaries

Pi publisher logs include:

- local offer SDP
- remote answer SDP
- local ICE candidates embedded in SDP
- remote ICE candidates from the browser
- peer connection, ICE connection, ICE gathering, and signaling state
- camera capture FPS, dropped old frames, JPEG decode time, and
  capture-to-encode-input handoff time
- outbound WebRTC frame rate, network send bitrate, packet rate, and encode time
  per frame when aiortc exposes it, tagged by camera

Browser logs include:

- signaling socket status
- remote offer SDP
- local answer SDP
- local and remote ICE candidates
- peer connection, ICE connection, ICE gathering, and signaling state
- receive frame rate, network receive bitrate, decode time, jitter-buffer delay,
  dropped frames, and packet loss, tagged by camera when browser stats expose it
- render frame rate, receive-to-render delay, capture-to-render delay when the
  browser exposes it, render queue delay, and processing time

## Low-Latency Defaults

- WebRTC camera defaults to `640x480` at `20 fps`.
- The Pi camera reader drains camera stdout continuously and keeps only the most
  recent frame.
- The aiortc `MediaRelay` subscriber is unbuffered, so slow viewers do not build
  per-viewer frame queues.
- The browser requests `playoutDelayHint=0` when supported.
- H.264 is preferred in codec negotiation. aiortc can only use hardware H.264 if
  the local encoder stack exposes it; otherwise it falls back to the available
  H.264 or VP8 implementation.

## Tuning Order

Less delay:

1. Keep `WEBRTC_CAMERA_WIDTH=640`, `WEBRTC_CAMERA_HEIGHT=480`, and
   `WEBRTC_CAMERA_FPS=20`.
2. Watch `droppedOldFrames`, `captureToEncodeInputMsAvg`, `networkSendKbps`,
   browser `jitterBufferMs`, and `receiveToRenderMs`.
3. If `captureToEncodeInputMsAvg` or `encodeMsPerFrame` grows, lower FPS before
   raising resolution.
4. If browser `jitterBufferMs` grows, lower resolution or move to a cleaner
   network path before increasing sharpness.

Better sharpness:

1. Try `WEBRTC_CAMERA_WIDTH=1280 WEBRTC_CAMERA_HEIGHT=720 WEBRTC_CAMERA_FPS=15`.
2. If delay stays acceptable, try `WEBRTC_CAMERA_FPS=20`.
3. Keep `WEBRTC_VIDEO_CODEC=H264` unless a browser/device behaves worse with it.

More stability:

1. Use `640x480` at `15 fps`.
2. Keep H.264 preferred, but try `WEBRTC_VIDEO_CODEC=VP8` if H.264 negotiation is
   unstable on a specific browser.
3. If ICE is unstable off-LAN, add TURN next; this pass intentionally does not
   add TURN yet.

## Operational Boundaries

- Both configured cameras publish by default; set `WEBRTC_CAMERA_NAMES=front`
  for one-camera bench tests.
- Robot controls still use the existing backend `/ws` path.
- The backend does not forward video media. It only forwards signaling.
- Backend-managed camera recording depends on the gateway JPEG frame path, not
  WebRTC media. Use `make pi-connect-esp` and open the browser with `?webrtc=0`
  when the rendered MP4 must include both camera feeds.
- TURN server support is not wired yet.

## Related Guides

- Complete robot bring-up: [Complete Robot Guide](./complete-robot.md)
- Backend protocol and recording API: [Backend Gateway](../backend/README.md)
- Pi gateway and run targets: [Raspberry Pi Robot Gateway](../pi/README.md)

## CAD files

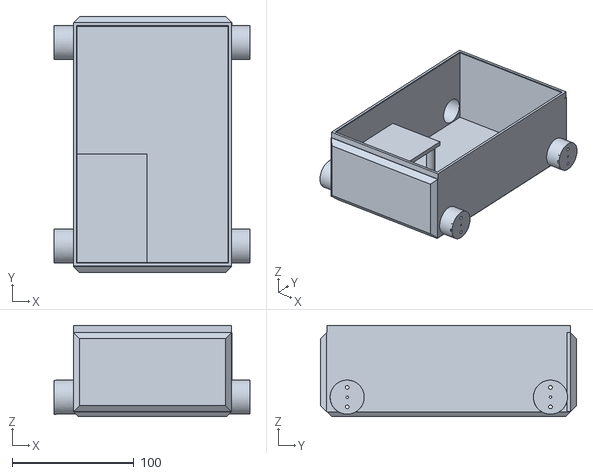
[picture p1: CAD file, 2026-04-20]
chasis/ProjectBasicFinal.stl
161.0 x 210.5 x 75.0

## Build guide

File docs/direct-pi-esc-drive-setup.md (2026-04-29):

# Direct Pi ESC Drive Setup

This is the legacy fallback path. The current preferred motor setup is
[ESP32 Serial ESC Control](./esp32-serial-esc-control.md), where the Pi sends
serial commands and the ESP32 generates the ESC pulses.

This document describes the fallback setup for driving two ESCs directly from
Raspberry Pi GPIO. It is not the complete robot's normal operating mode.

## Topology

The supported control path is:

`web app -> backend -> pi/gateway.py -> left/right ESC signal pulses`

In this setup:

- The PC runs the backend and serves the web app.
- The Raspberry Pi runs `pi/gateway.py`.
- The Pi connects to the PC backend over LAN or Tailscale.
- The Pi generates RC-style control pulses for the left and right ESCs.
- The front camera, rear camera, and LiDAR stay attached to the Pi.
- The ESP32 path is not used.

For the complete robot operating sequence, use
[Complete Robot Guide](./complete-robot.md).

## Supported Hardware

Use this document only if your motor controllers accept standard RC servo-style
pulses. DShot-only ESCs are not compatible with this path.

Expected hardware:

- Raspberry Pi 5
- Two ESCs that accept RC pulse input
- Two drive motors
- Robot battery or motor power distribution for the ESCs
- Separate regulated 5V supply for the Pi
- Common ground between the Pi and both ESCs
- Two Pi cameras
- USB LiDAR connected to the Pi

## Exact Wiring

### ESC signal wiring

Connect the ESC receiver leads like this:

| Connection | Pi pin |
| --- | --- |
| Left ESC signal | `GPIO18` / physical pin `12` |
| Right ESC signal | `GPIO19` / physical pin `35` |
| Left ESC ground | any Pi ground |
| Right ESC ground | any Pi ground |

Recommended receiver-lead handling:

- Connect `signal` and `ground` from each ESC to the Pi.
- Leave ESC `5V/BEC` disconnected from the Pi.
- Do not feed 5V into any Pi GPIO pin.
- Do not tie multiple ESC BEC outputs together.

### ESC and motor power wiring

Connect the power side like this:

- ESC main battery leads -> robot battery or power distribution bus
- Motor phase wires -> each ESC's motor outputs
- Pi power -> its own regulated 5V supply

Required power rule:

- The Pi and both ESCs must share ground.

Do not do this:

- Do not power the motors from the Pi.
- Do not backfeed ESC battery voltage into the Pi.
- Do not use Pi GPIO as a motor power source.

## Camera and LiDAR Layout

This repo assumes:

- Front camera on Pi camera index `0`
- Back camera on Pi camera index `1`
- LiDAR connected over USB serial, typically `/dev/ttyUSB0`

When the back camera is the active primary view, the frontend flips the LiDAR
view by 180 degrees. Drive controls stay robot-relative: the right arrow sends
robot `right`, the left arrow sends robot `left`, and camera selection does not
change motor direction.

## PC Setup

From the repo root on the PC:

```bash
make pc-start
```

Default services:

- Backend: `0.0.0.0:3000`
- Web app: `http://127.0.0.1:8080`

You then use the browser on that PC to open the web app.

Before starting the Pi, confirm the Pi can reach the PC backend:

```bash
curl http://<pc-ip>:3000/health
```

If that fails on your network, use Tailscale or a network that allows
device-to-device traffic.

## Pi Software Setup

From the repo root on the Pi:

```bash
sudo apt-get install -y swig build-essential python3-dev liblgpio-dev
python3 -m venv .venv
source .venv/bin/activate
make pi-setup
```

Direct GPIO pulse output uses the native `lgpio` library. Install those system
packages before `make pi-setup` so the Python package can build.

## Start the Pi in ESC Mode

Use the helper target:

```bash
make pi-connect-esc PC_IP=<pc-ip>
```

That starts the gateway with the direct-ESC path and points it at the PC
backend on port `3000`.

Equivalent manual command:

```bash
BACKEND_WS_BASE=ws://<pc-ip>:3000 PI_MOTOR_DRIVER=esc python3 pi/gateway.py
```

## Runtime Control Flow

The runtime behavior is intentionally conservative:

1. The Pi starts with both ESC outputs held at neutral.
2. The browser requests `motor.status`.
3. Arrow keys stay disabled until the Pi reports the ESC driver is ready.
4. You click `Arm Motors`.
5. The Pi holds the arm pulse for the arm delay.
6. Only after the Pi reports `ARMED` does the UI enable driving.
7. While a key is held, the browser refreshes `drive` commands repeatedly.
8. If refreshes stop, the Pi watchdog returns both ESCs to neutral.

This is how the repo avoids a stale drive command continuing after focus loss,
network loss, or browser interruption.

## Drive Mapping

- `Up`: both motors forward
- `Down`: both motors reverse if `ESC_BIDIRECTIONAL=1`
- `Left`: spin left with bidirectional ESCs, or pivot left with forward-only ESCs
- `Right`: spin right with bidirectional ESCs, or pivot right with forward-only ESCs

The mapping is the same for the front and back camera views. The frontend sends
the same four robot directions in all camera modes: `forward`, `reverse`,
`left`, and `right`.

## What the Pi Sends to the ESCs

Default pulse behavior:

- Neutral pulse: `1000 us`
- Arm pulse: `1000 us`
- Forward pulse range: `1100 us` to `2000 us`
- Reverse pulse range: disabled by default
- Arm delay: `3.0 s`
- Watchdog timeout: `3000 ms`
- Max speed clamp: `0.15`
- Update rate: `50 Hz`
- Servo signal frequency: `50 Hz`
- Pulse refresh: disabled by default

Directional mixing in the Pi controller:

- `forward`: left forward, right forward
- `reverse`: left reverse, right reverse
- `left`: left reverse and right forward when bidirectional; otherwise left neutral and right forward
- `right`: left forward and right reverse when bidirectional; otherwise left forward and right neutral

If one side of the drivetrain is mechanically mirrored, set
`ESC_LEFT_INVERTED=1` or `ESC_RIGHT_INVERTED=1`. Do not change the Pi pin
mapping for that case.

## Drive Environment Variables

These are the drive-related variables used by the Pi gateway:

| Variable | Default | Purpose |
| --- | --- | --- |
| `PI_MOTOR_DRIVER` | `esc` for this setup | Select direct Pi ESC mode |
| `ESC_LEFT_GPIO` | `18` | Left ESC signal pin |
| `ESC_RIGHT_GPIO` | `19` | Right ESC signal pin |
| `ESC_GPIOCHIP` | `-1` | Auto-try `gpiochip4`, then `gpiochip0`; set explicitly if needed |
| `ESC_LEFT_INVERTED` | `0` | Invert left side direction if needed |
| `ESC_RIGHT_INVERTED` | `0` | Invert right side direction if needed |
| `ESC_BIDIRECTIONAL` | `0` | Enable reverse pulses |
| `ESC_ARM_PULSE_US` | `1000` | Pulse held during arming |
| `ESC_NEUTRAL_PULSE_US` | `1000` | Neutral pulse |
| `ESC_FORWARD_MIN_PULSE_US` | `1100` | Minimum forward pulse |
| `ESC_FORWARD_MAX_PULSE_US` | `2000` | Maximum forward pulse |
| `ESC_REVERSE_MIN_PULSE_US` | `1440` | Minimum reverse pulse |
| `ESC_REVERSE_MAX_PULSE_US` | `1100` | Maximum reverse pulse |
| `ESC_ARM_DELAY_SEC` | `3.0` | Time spent arming before drive is allowed |
| `ESC_WATCHDOG_TIMEOUT_MS` | `3000` | Failsafe timeout to return to neutral |
| `ESC_MAX_SPEED` | `0.15` | Max UI-requested speed allowed by the Pi |
| `ESC_RAMP_STEP_US` | `8` | Pulse ramping step |
| `ESC_UPDATE_HZ` | `50` | Pulse update loop rate |
| `ESC_SERVO_FREQUENCY_HZ` | `50` | ESC servo pulse frequency |
| `ESC_PULSE_REFRESH_MS` | `0` | Re-issue current pulses while holding a drive command; `0` disables refresh |

## Bidirectional ESCs

If your ESCs are bidirectional car ESCs instead of forward-only ESCs, start with
this configuration:

```bash
PI_MOTOR_DRIVER=esc \
ESC_BIDIRECTIONAL=1 \
ESC_ARM_PULSE_US=1500 \
ESC_NEUTRAL_PULSE_US=1500 \
ESC_FORWARD_MIN_PULSE_US=1560 \
ESC_FORWARD_MAX_PULSE_US=1900 \
python3 pi/gateway.py
```

With the default forward-only mode:

- `Down` cannot command reverse
- `Left` and `Right` become pivots instead of full spins

## Bring-Up Checklist

Use this order when you first power the drivetrain:

1. Put the robot on a stand or otherwise keep the drive wheels off the ground.
2. Verify the PC backend is running.
3. Verify `curl http://<pc-ip>:3000/health` works from the Pi.
4. Make sure `lgpio` imports inside the Pi virtual environment.
5. Start the Pi in ESC mode.
6. Open the web app on the PC.
7. Wait for the motor panel to show the Pi as connected.
8. Click `Arm Motors`.
9. Wait for `ARMED`.
10. Test `Up` at low speed.
11. If one side spins the wrong way, use `ESC_LEFT_INVERTED` or `ESC_RIGHT_INVERTED`.
12. Test `Left`, `Right`, and release-to-stop behavior.
13. Confirm the robot returns to neutral when the key is released or the browser loses focus.

## Recommended First Tests

Before driving with motors live, it is useful to confirm the command path in
echo mode:

```bash
make pi-connect-echo PC_IP=<pc-ip>
```

That lets you verify:

- The Pi reaches the backend
- The web app can command the Pi
- The correct directions are being generated

After that, switch to ESC mode and start with a lower speed cap, for example:

```bash
BACKEND_WS_BASE=ws://<pc-ip>:3000 PI_MOTOR_DRIVER=esc ESC_MAX_SPEED=0.15 python3 pi/gateway.py
```

## Failure Modes to Check First

If the robot does not drive correctly, check these in order:

- No movement at all: `lgpio` cannot open the GPIO chip, wrong GPIO pins, or ESC ground is not shared with the Pi
- Motor panel never becomes ready: Pi cannot reach backend, or ESC driver could not initialize
- One side spins backward on `Up`: set `ESC_LEFT_INVERTED=1` or `ESC_RIGHT_INVERTED=1`
- Reverse does nothing: your ESC is likely forward-only and should use `ESC_BIDIRECTIONAL=0`
- Robot keeps moving after command loss: verify the Pi watchdog is active and command refresh has not been modified
- Camera view feels backward: use the camera switch button; drive commands remain robot-relative in every camera view

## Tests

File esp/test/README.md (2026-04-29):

# test

No PlatformIO unit tests are checked in yet. Use this directory for firmware
tests if the ESP32 control logic is split into testable modules later.

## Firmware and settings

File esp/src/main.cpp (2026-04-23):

#include <Arduino.h>
#include <ctype.h>
#include <math.h>
#include <stdlib.h>
#include <string.h>

// ESP32 ESC signal wiring. Override these with PlatformIO build_flags if your
// board layout uses different GPIOs.
#ifndef LEFT_ESC_PIN
#define LEFT_ESC_PIN 18
#endif

#ifndef RIGHT_ESC_PIN
#define RIGHT_ESC_PIN 19
#endif

#ifndef ESC_BIDIRECTIONAL
#define ESC_BIDIRECTIONAL 0
#endif

#ifndef ESC_LEFT_INVERTED
#define ESC_LEFT_INVERTED 0
#endif

#ifndef ESC_RIGHT_INVERTED
#define ESC_RIGHT_INVERTED 0
#endif

#ifndef ESC_ARM_PULSE_US
#define ESC_ARM_PULSE_US 1000
#endif

#ifndef ESC_NEUTRAL_PULSE_US
#define ESC_NEUTRAL_PULSE_US 1000
#endif

#ifndef ESC_FORWARD_MIN_PULSE_US
#define ESC_FORWARD_MIN_PULSE_US 1100
#endif

#ifndef ESC_FORWARD_MAX_PULSE_US
#define ESC_FORWARD_MAX_PULSE_US 2000
#endif

#ifndef ESC_REVERSE_MIN_PULSE_US
#define ESC_REVERSE_MIN_PULSE_US 1440
#endif

#ifndef ESC_REVERSE_MAX_PULSE_US
#define ESC_REVERSE_MAX_PULSE_US 1100
#endif

#ifndef ESC_ARM_DELAY_MS
#define ESC_ARM_DELAY_MS 3000
#endif

#ifndef ESC_WATCHDOG_TIMEOUT_MS
#define ESC_WATCHDOG_TIMEOUT_MS 3000
#endif

#ifndef ESC_MAX_SPEED
#define ESC_MAX_SPEED 0.15f
#endif

#ifndef ESC_RAMP_STEP_US
#define ESC_RAMP_STEP_US 8
#endif

#ifndef ESC_UPDATE_HZ
#define ESC_UPDATE_HZ 50
#endif

constexpr int kLeftEscPin = LEFT_ESC_PIN;
constexpr int kRightEscPin = RIGHT_ESC_PIN;
constexpr int kLeftEscChannel = 0;
constexpr int kRightEscChannel = 1;
constexpr int kServoFrequencyHz = 50;
constexpr int kPwmResolutionBits = 16;
constexpr uint32_t kPwmMaxDuty = (1UL << kPwmResolutionBits) - 1;
constexpr int kServoPeriodUs = 1000000 / kServoFrequencyHz;
constexpr int kMinPulseUs = 900;
constexpr int kMaxPulseUs = 2100;
constexpr bool kBidirectional = ESC_BIDIRECTIONAL != 0;
constexpr bool kLeftInverted = ESC_LEFT_INVERTED != 0;
constexpr bool kRightInverted = ESC_RIGHT_INVERTED != 0;
constexpr int kArmPulseUs = ESC_ARM_PULSE_US;
constexpr int kNeutralPulseUs = ESC_NEUTRAL_PULSE_US;
constexpr int kForwardMinPulseUs = ESC_FORWARD_MIN_PULSE_US;
constexpr int kForwardMaxPulseUs = ESC_FORWARD_MAX_PULSE_US;
constexpr int kReverseMinPulseUs = ESC_REVERSE_MIN_PULSE_US;
constexpr int kReverseMaxPulseUs = ESC_REVERSE_MAX_PULSE_US;
constexpr unsigned long kArmDelayMs = ESC_ARM_DELAY_MS;
constexpr unsigned long kWatchdogTimeoutMs = ESC_WATCHDOG_TIMEOUT_MS;
constexpr float kMaxSpeed = ESC_MAX_SPEED;
constexpr int kRampStepUs = ESC_RAMP_STEP_US;
constexpr unsigned long kUpdateIntervalMs = 1000UL / ESC_UPDATE_HZ;
constexpr unsigned long kStatusPublishIntervalMs = 1000;
constexpr unsigned long kDirtyStatusPublishIntervalMs = 250;
constexpr size_t kSerialLineBufferSize = 256;

enum class MotorState {
    Disarmed,
    Arming,
    Armed
};

char serialLineBuffer[kSerialLineBufferSize] = {0};
size_t serialLineLength = 0;
MotorState motorState = MotorState::Disarmed;
int currentLeftPulseUs = kNeutralPulseUs;
int currentRightPulseUs = kNeutralPulseUs;
int targetLeftPulseUs = kNeutralPulseUs;
int targetRightPulseUs = kNeutralPulseUs;
unsigned long armingCompleteAtMs = 0;
unsigned long commandDeadlineAtMs = 0;
unsigned long lastOutputUpdateMs = 0;
unsigned long lastStatusPublishMs = 0;
bool commandDeadlineActive = false;
bool statusDirty = true;
char activeDirection[12] = "stop";
char lastError[96] = "";

int clampInt(int value, int minimum, int maximum) {
    if (value < minimum) {
        return minimum;
    }
    if (value > maximum) {
        return maximum;
    }
    return value;
}

float clampFloat(float value, float minimum, float maximum) {
    if (value < minimum) {
        return minimum;
    }
    if (value > maximum) {
        return maximum;
    }
    return value;
}

int lerpInt(int start, int end, float ratio) {
    const float boundedRatio = clampFloat(ratio, 0.0f, 1.0f);
    return static_cast<int>(roundf(static_cast<float>(start) + static_cast<float>(end - start) * boundedRatio));
}

int moveTowards(int current, int target, int maximumStep) {
    if (current < target) {
        return min(target, current + maximumStep);
    }
    if (current > target) {
        return max(target, current - maximumStep);
    }
    return target;
}

void setLastError(const char *message) {
    if (message == nullptr || message[0] == '\0') {
        lastError[0] = '\0';
        return;
    }
    strncpy(lastError, message, sizeof(lastError) - 1);
    lastError[sizeof(lastError) - 1] = '\0';
}

void setActiveDirection(const char *direction) {
    strncpy(activeDirection, direction, sizeof(activeDirection) - 1);
    activeDirection[sizeof(activeDirection) - 1] = '\0';
}

uint32_t dutyForPulseUs(int pulseUs) {
    const int boundedPulseUs = clampInt(pulseUs, 0, kMaxPulseUs);
    return static_cast<uint32_t>((static_cast<uint64_t>(boundedPulseUs) * kPwmMaxDuty) / kServoPeriodUs);
}

void writeEscPulse(int channel, int pulseUs) {
    ledcWrite(channel, dutyForPulseUs(pulseUs));
}

void applyCurrentPulses() {
    writeEscPulse(kLeftEscChannel, currentLeftPulseUs);
    writeEscPulse(kRightEscChannel, currentRightPulseUs);
}

void forcePulses(int leftPulseUs, int rightPulseUs) {
    currentLeftPulseUs = clampInt(leftPulseUs, kMinPulseUs, kMaxPulseUs);
    currentRightPulseUs = clampInt(rightPulseUs, kMinPulseUs, kMaxPulseUs);
    targetLeftPulseUs = currentLeftPulseUs;
    targetRightPulseUs = currentRightPulseUs;
    applyCurrentPulses();
}

void setTargetPulses(int leftPulseUs, int rightPulseUs) {
    targetLeftPulseUs = clampInt(leftPulseUs, kMinPulseUs, kMaxPulseUs);
    targetRightPulseUs = clampInt(rightPulseUs, kMinPulseUs, kMaxPulseUs);
}

void writeJsonString(const char *value) {
    Serial.print('"');
    for (const char *cursor = value; cursor != nullptr && *cursor != '\0'; ++cursor) {
        const char ch = *cursor;
        if (ch == '"' || ch == '\\') {
            Serial.print('\\');
            Serial.print(ch);
        } else if (static_cast<unsigned char>(ch) < 0x20) {
            Serial.print(' ');
        } else {
            Serial.print(ch);
        }
    }
    Serial.print('"');
}

void publishAck(const char *id, const char *status, const char *command, const char *detailsJson = nullptr) {
    Serial.print("{\"type\":\"ack\",\"id\":");
    writeJsonString(id != nullptr ? id : "");
    Serial.print(",\"status\":");
    writeJsonString(status);
    Serial.print(",\"command\":");
    writeJsonString(command);
    if (detailsJson != nullptr && detailsJson[0] != '\0') {
        Serial.print(",\"details\":");
        Serial.print(detailsJson);
    }
    Serial.println("}");
}

bool isArming() {
    return motorState == MotorState::Arming;
}

bool isArmed() {
    return motorState == MotorState::Armed;
}

void publishMotorStatus(const char *reason = nullptr) {
    const bool arming = isArming();
    const bool armed = isArmed();
    const bool ready = armed && !arming;

    Serial.print("{\"type\":\"motor.status\",\"driver\":\"esp\",\"driverAvailable\":true");
    Serial.print(",\"requiresArm\":true");
    Serial.print(",\"armed\":");
    Serial.print(armed ? "true" : "false");
    Serial.print(",\"arming\":");
    Serial.print(arming ? "true" : "false");
    Serial.print(",\"readyForDrive\":");
    Serial.print(ready ? "true" : "false");
    Serial.print(",\"bidirectional\":");
    Serial.print(kBidirectional ? "true" : "false");
    Serial.print(",\"direction\":");
    writeJsonString(activeDirection);
    Serial.print(",\"maxSpeed\":");
    Serial.print(kMaxSpeed, 3);
    Serial.print(",\"watchdogTimeoutMs\":");
    Serial.print(kWatchdogTimeoutMs);
    Serial.print(",\"pins\":{\"leftSignalGpio\":");
    Serial.print(kLeftEscPin);
    Serial.print(",\"rightSignalGpio\":");
    Serial.print(kRightEscPin);
    Serial.print("},\"pulseWidthsUs\":{\"arm\":");
    Serial.print(kArmPulseUs);
    Serial.print(",\"neutral\":");
    Serial.print(kNeutralPulseUs);
    Serial.print(",\"forwardMin\":");
    Serial.print(kForwardMinPulseUs);
    Serial.print(",\"forwardMax\":");
    Serial.print(kForwardMaxPulseUs);
    Serial.print(",\"reverseMin\":");
    Serial.print(kReverseMinPulseUs);
    Serial.print(",\"reverseMax\":");
    Serial.print(kReverseMaxPulseUs);
    Serial.print(",\"currentLeft\":");
    Serial.print(currentLeftPulseUs);
    Serial.print(",\"currentRight\":");
    Serial.print(currentRightPulseUs);
    Serial.print(",\"targetLeft\":");
    Serial.print(targetLeftPulseUs);
    Serial.print(",\"targetRight\":");
    Serial.print(targetRightPulseUs);
    Serial.print("},\"signal\":{\"servoFrequencyHz\":");
    Serial.print(kServoFrequencyHz);
    Serial.print(",\"resolutionBits\":");
    Serial.print(kPwmResolutionBits);
    Serial.print(",\"rampStepUs\":");
    Serial.print(kRampStepUs);
    Serial.print("},\"lastError\":");
    if (lastError[0] == '\0') {
        Serial.print("null");
    } else {
        writeJsonString(lastError);
    }
    if (reason != nullptr && reason[0] != '\0') {
        Serial.print(",\"reason\":");
        writeJsonString(reason);
    }
    Serial.println("}");

    lastStatusPublishMs = millis();
    statusDirty = false;
}

void markStatusDirty() {
    statusDirty = true;
}

const char *findJsonKeyValueStart(const char *line, const char *key) {
    char pattern[32];
    snprintf(pattern, sizeof(pattern), "\"%s\"", key);
    const size_t patternLength = strlen(pattern);
    const char *searchFrom = line;

    while (searchFrom != nullptr && *searchFrom != '\0') {
        const char *keyStart = strstr(searchFrom, pattern);
        if (keyStart == nullptr) {
            return nullptr;
        }

        const char *prefix = keyStart;
        while (prefix > line && isspace(static_cast<unsigned char>(prefix[-1]))) {
            --prefix;
        }

        const bool looksLikeObjectKey =
            prefix == line ||
            prefix[-1] == '{' ||
            prefix[-1] == ',';

        const char *cursor = keyStart + patternLength;
        while (*cursor != '\0' && isspace(static_cast<unsigned char>(*cursor))) {
            ++cursor;
        }

        if (looksLikeObjectKey && *cursor == ':') {
            ++cursor;
            while (*cursor != '\0' && isspace(static_cast<unsigned char>(*cursor))) {
                ++cursor;
            }
            return cursor;
        }

        searchFrom = keyStart + patternLength;
    }

    return nullptr;
}

bool extractJsonString(const char *line, const char *key, char *out, size_t outSize) {
    if (outSize == 0) {
        return false;
    }

    const char *cursor = findJsonKeyValueStart(line, key);
    if (cursor == nullptr || *cursor != '"') {
        return false;
    }
    ++cursor;

    size_t length = 0;
    while (*cursor != '\0' && *cursor != '"') {
        char ch = *cursor;
        if (ch == '\\' && cursor[1] != '\0') {
            ++cursor;
            ch = *cursor;
        }
        if (length < outSize - 1) {
            out[length++] = ch;
        }
        ++cursor;
    }
    out[length] = '\0';
    return *cursor == '"';
}

bool extractJsonFloat(const char *line, const char *key, float &out) {
    const char *cursor = findJsonKeyValueStart(line, key);
    if (cursor == nullptr) {
        return false;
    }

    char *end = nullptr;
    const float parsed = strtof(cursor, &end);
    if (end == cursor) {
        return false;
    }
    out = parsed;
    return true;
}

bool extractJsonInt(const char *line, const char *key, int &out) {
    const char *cursor = findJsonKeyValueStart(line, key);
    if (cursor == nullptr) {
        return false;
    }

    char *end = nullptr;
    const long parsed = strtol(cursor, &end, 10);
    if (end == cursor) {
        return false;
    }
    out = static_cast<int>(parsed);
    return true;
}

bool isDriveDirection(const char *direction) {
    return strcmp(direction, "forward") == 0 ||
           strcmp(direction, "reverse") == 0 ||
           strcmp(direction, "left") == 0 ||
           strcmp(direction, "right") == 0;
}

int pulseForSignedSpeed(float signedSpeed) {
    if (fabsf(signedSpeed) < 1e-6f) {
        return kNeutralPulseUs;
    }

    if (signedSpeed > 0.0f) {
        return lerpInt(kForwardMinPulseUs, kForwardMaxPulseUs, fabsf(signedSpeed));
    }

    if (!kBidirectional) {
        return kNeutralPulseUs;
    }

    return lerpInt(kReverseMinPulseUs, kReverseMaxPulseUs, fabsf(signedSpeed));
}

float signedSpeedForSide(const char *direction, bool leftSide, float speedRatio) {
    float signedSpeed = 0.0f;

    if (strcmp(direction, "forward") == 0) {
        signedSpeed = speedRatio;
    } else if (strcmp(direction, "reverse") == 0) {
        signedSpeed = kBidirectional ? -speedRatio : 0.0f;
    } else if (strcmp(direction, "left") == 0) {
        signedSpeed = (kBidirectional && leftSide) ? -speedRatio : (!leftSide ? speedRatio : 0.0f);
    } else if (strcmp(direction, "right") == 0) {
        signedSpeed = leftSide ? speedRatio : (kBidirectional ? -speedRatio : 0.0f);
    }

    const bool inverted = leftSide ? kLeftInverted : kRightInverted;
    if (inverted && !kBidirectional) {
        return signedSpeed;
    }
    return inverted ? -signedSpeed : signedSpeed;
}

void stopMotors(const char *reason) {
    commandDeadlineActive = false;
    setActiveDirection("stop");
    setTargetPulses(kNeutralPulseUs, kNeutralPulseUs);
    setLastError("");
    markStatusDirty();
    if (reason != nullptr && strcmp(reason, "watchdog_timeout") == 0) {
        publishMotorStatus(reason);
    }
}

void beginArm(const char *id) {
    motorState = MotorState::Arming;
    armingCompleteAtMs = millis() + kArmDelayMs;
    commandDeadlineActive = false;
    setActiveDirection("stop");
    setLastError("");
    forcePulses(kArmPulseUs, kArmPulseUs);
    publishAck(id, "arming_started", "arm_motors");
    publishMotorStatus("arming_started");
}

void disarmMotors(const char *id, const char *reason = "manual") {
    motorState = MotorState::Disarmed;
    armingCompleteAtMs = 0;
    commandDeadlineActive = false;
    setActiveDirection("stop");
    setLastError("");
    forcePulses(kNeutralPulseUs, kNeutralPulseUs);
    publishAck(id, "motor_disarmed", "disarm_motors");
    publishMotorStatus(reason);
}

void applyDriveCommand(const char *id, const char *direction, float requestedSpeed, int durationMs) {
    if (!isDriveDirection(direction)) {
        setLastError("invalid drive direction");
        publishAck(id, "invalid_drive_direction", "drive");
        publishMotorStatus("invalid_drive_direction");
        return;
    }

    if (isArming()) {
        publishAck(id, "motor_arming", "drive");
        return;
    }

    if (!isArmed()) {
        publishAck(id, "motor_not_armed", "drive");
        return;
    }

    if (strcmp(direction, "reverse") == 0 && !kBidirectional) {
        stopMotors("reverse_disabled");
        publishAck(id, "reverse_unsupported", "drive");
        return;
    }

    const float appliedSpeed = min(clampFloat(requestedSpeed, 0.0f, 1.0f), kMaxSpeed);
    if (appliedSpeed <= 0.0f) {
        stopMotors("zero_speed");
        return;
    }

    const int leftPulseUs = pulseForSignedSpeed(signedSpeedForSide(direction, true, appliedSpeed));
    const int rightPulseUs = pulseForSignedSpeed(signedSpeedForSide(direction, false, appliedSpeed));
    const int ttlMs = clampInt(durationMs > 0 ? durationMs : static_cast<int>(kWatchdogTimeoutMs), 100, 5000);

    const bool changed = leftPulseUs != targetLeftPulseUs ||
                         rightPulseUs != targetRightPulseUs ||
                         strcmp(activeDirection, direction) != 0;

    setTargetPulses(leftPulseUs, rightPulseUs);
    setActiveDirection(direction);
    commandDeadlineAtMs = millis() + static_cast<unsigned long>(ttlMs);
    commandDeadlineActive = true;
    setLastError("");
    if (changed) {
        markStatusDirty();
    }
}

void completeArmingIfReady(unsigned long now) {
    if (!isArming()) {
        return;
    }

    if (static_cast<long>(now - armingCompleteAtMs) < 0) {
        return;
    }

    motorState = MotorState::Armed;
    armingCompleteAtMs = 0;
    setActiveDirection("stop");
    setTargetPulses(kNeutralPulseUs, kNeutralPulseUs);
    publishMotorStatus("armed");
}

void enforceWatchdog(unsigned long now) {
    if (!commandDeadlineActive) {
        return;
    }

    if (static_cast<long>(now - commandDeadlineAtMs) >= 0) {
        stopMotors("watchdog_timeout");
    }
}

void updateOutputs(unsigned long now) {
    if (lastOutputUpdateMs == 0) {
        lastOutputUpdateMs = now;
    }

    if (now - lastOutputUpdateMs < kUpdateIntervalMs) {
        return;
    }
    lastOutputUpdateMs = now;

    const int nextLeft = moveTowards(currentLeftPulseUs, targetLeftPulseUs, kRampStepUs);
    const int nextRight = moveTowards(currentRightPulseUs, targetRightPulseUs, kRampStepUs);
    if (nextLeft == currentLeftPulseUs && nextRight == currentRightPulseUs) {
        return;
    }

    currentLeftPulseUs = nextLeft;
    currentRightPulseUs = nextRight;
    applyCurrentPulses();
    markStatusDirty();
}

void maybePublishStatus(unsigned long now) {
    const bool periodicStatusDue = now - lastStatusPublishMs >= kStatusPublishIntervalMs;
    const bool dirtyStatusDue = statusDirty && now - lastStatusPublishMs >= kDirtyStatusPublishIntervalMs;
    if (dirtyStatusDue || periodicStatusDue) {
        publishMotorStatus();
    }
}

void handleCommandLine(const char *line) {
    char command[32] = "";
    char id[64] = "";
    extractJsonString(line, "id", id, sizeof(id));

    if (!extractJsonString(line, "command", command, sizeof(command))) {
        return;
    }

    if (strcmp(command, "motor_status") == 0) {
        publishAck(id, "motor_status_sent", command);
        publishMotorStatus("requested");
        return;
    }

    if (strcmp(command, "arm_motors") == 0) {
        beginArm(id);
        return;
    }

    if (strcmp(command, "disarm_motors") == 0) {
        disarmMotors(id);
        return;
    }

    if (strcmp(command, "stop") == 0) {
        stopMotors("commanded_stop");
        publishAck(id, "motor_stopped", command);
        publishMotorStatus("commanded_stop");
        return;
    }

    if (strcmp(command, "drive") == 0) {
        char direction[16] = "";
        float speed = 0.0f;
        int durationMs = static_cast<int>(kWatchdogTimeoutMs);

        extractJsonString(line, "direction", direction, sizeof(direction));
        extractJsonFloat(line, "speed", speed);
        extractJsonInt(line, "durationMs", durationMs);
        applyDriveCommand(id, direction, speed, durationMs);
        return;
    }

    publishAck(id, "unsupported_motor_command", command);
}

void flushSerialLineBuffer() {
    if (serialLineLength == 0) {
        return;
    }
    serialLineBuffer[serialLineLength] = '\0';
    handleCommandLine(serialLineBuffer);
    serialLineLength = 0;
}

void processSerialByte(char ch) {
    if (ch == '\r') {
        return;
    }
    if (ch == '\n') {
        flushSerialLineBuffer();
        return;
    }

    if (serialLineLength < kSerialLineBufferSize - 1) {
        serialLineBuffer[serialLineLength++] = ch;
    } else {
        serialLineLength = 0;
        setLastError("serial line too long");
        markStatusDirty();
    }
}

void setup() {
    ledcSetup(kLeftEscChannel, kServoFrequencyHz, kPwmResolutionBits);
    ledcSetup(kRightEscChannel, kServoFrequencyHz, kPwmResolutionBits);
    ledcAttachPin(kLeftEscPin, kLeftEscChannel);
    ledcAttachPin(kRightEscPin, kRightEscChannel);
    forcePulses(kNeutralPulseUs, kNeutralPulseUs);

    Serial.begin(115200);
    delay(200);
    publishMotorStatus("boot");
}

void loop() {
    while (Serial.available() > 0) {
        processSerialByte(static_cast<char>(Serial.read()));
    }

    const unsigned long now = millis();
    completeArmingIfReady(now);
    enforceWatchdog(now);
    updateOutputs(now);
    maybePublishStatus(now);
}

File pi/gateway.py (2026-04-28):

#!/usr/bin/env python3
"""
Raspberry Pi gateway base:
- Connects to backend WebSocket as role=pi
- Forwards UI drive commands to ESP32 over serial
- Publishes ESP32 telemetry to backend
- Publishes dual-camera status to backend
- Streams live JPEG frames for both Pi cameras
- Streams LiDAR scans to backend for web visualization
"""

from __future__ import annotations

import asyncio
import base64
import json
import logging
import os
import shutil
import subprocess
import threading
import time
from dataclasses import dataclass
from datetime import datetime, timezone
from typing import Any, Dict, Iterator, List, Optional, Tuple
from urllib.parse import urlencode

import websockets
from websockets.exceptions import ConnectionClosed

try:
    import serial  # type: ignore
except ImportError:  # pragma: no cover
    serial = None

try:
    import cv2  # type: ignore
except ImportError:  # pragma: no cover
    cv2 = None

try:
    from rplidar import RPLidar  # type: ignore
except ImportError:  # pragma: no cover
    RPLidar = None

try:
    import lgpio  # type: ignore
except ImportError:  # pragma: no cover
    lgpio = None

from serial_devices import choose_serial_port, list_serial_ports, same_serial_device


JsonDict = Dict[str, Any]

CPU_TEMPERATURE_PATH = "/sys/class/thermal/thermal_zone0/temp"
MOTOR_DRIVER_ECHO = "echo"
MOTOR_DRIVER_ESP = "esp"
MOTOR_DRIVER_ESC = "esc"
SUPPORTED_MOTOR_DRIVERS = {MOTOR_DRIVER_ECHO, MOTOR_DRIVER_ESP, MOTOR_DRIVER_ESC}
ESP_MOTOR_STATUS_STALE_SEC = 3.0


def now_iso() -> str:
    return datetime.now(timezone.utc).isoformat()


def celsius_to_fahrenheit(celsius: float) -> float:
    return (celsius * 9.0 / 5.0) + 32.0


def env_flag(name: str, default: bool = False) -> bool:
    raw = os.getenv(name)
    if raw is None:
        return default
    return raw.strip().lower() not in {"0", "false", "no", "off", ""}


def env_int(name: str, default: int) -> int:
    return int(os.getenv(name, str(default)))


def env_float(name: str, default: float) -> float:
    return float(os.getenv(name, str(default)))


def env_int_any(names: Tuple[str, ...], default: int) -> int:
    for name in names:
        raw = os.getenv(name)
        if raw is None:
            continue
        return int(raw)
    return default


def env_choice(name: str, default: str, allowed: set[str]) -> str:
    raw = os.getenv(name, default)
    normalized = raw.strip().lower()
    return normalized if normalized in allowed else default


def close_quietly(resource: Any, method_name: str) -> None:
    method = getattr(resource, method_name, None)
    if callable(method):
        try:
            method()
        except Exception:
            pass


@dataclass(frozen=True)
class Config:
    backend_ws_base: str
    device_id: str
    device_token: str
    esp_serial_port: str
    esp_baud: int
    motor_driver: str
    motor_echo: bool
    motor_echo_only: bool
    esc_left_gpio: int
    esc_right_gpio: int
    esc_gpiochip: int
    esc_left_inverted: bool
    esc_right_inverted: bool
    esc_bidirectional: bool
    esc_arm_pulse_us: int
    esc_neutral_pulse_us: int
    esc_forward_min_pulse_us: int
    esc_forward_max_pulse_us: int
    esc_reverse_min_pulse_us: int
    esc_reverse_max_pulse_us: int
    esc_arm_delay_sec: float
    esc_watchdog_timeout_ms: int
    esc_max_speed: float
    esc_ramp_step_us: int
    esc_update_hz: float
    esc_servo_frequency_hz: int
    esc_pulse_refresh_ms: int
    camera_front_index: int
    camera_back_index: int
    heartbeat_interval_sec: float
    camera_publish_interval_sec: float
    camera_stream_hz: float
    camera_frame_width: int
    camera_frame_height: int
    camera_jpeg_quality: int
    camera_jpeg_enabled: bool
    lidar_enabled: bool
    lidar_port: str
    lidar_max_distance_mm: int
    lidar_min_distance_mm: int
    lidar_max_points: int
    lidar_publish_hz: float
    reconnect_max_sec: float

    @property
    def ws_url(self) -> str:
        base = self.backend_ws_base.rstrip("/")
        params = {"role": "pi", "deviceId": self.device_id}
        if self.device_token:
            params["token"] = self.device_token
        return f"{base}/ws?{urlencode(params)}"

    @staticmethod
    def from_env() -> "Config":
        motor_echo = env_flag("PI_MOTOR_ECHO", default=True)
        motor_echo_only = env_flag("PI_MOTOR_ECHO_ONLY", default=False)
        legacy_motor_driver = MOTOR_DRIVER_ECHO if motor_echo_only else MOTOR_DRIVER_ESP
        motor_driver = env_choice("PI_MOTOR_DRIVER", legacy_motor_driver, SUPPORTED_MOTOR_DRIVERS)
        lidar_enabled = env_flag("LIDAR_ENABLED", default=env_flag("PI_LIDAR_ENABLED", default=True))
        explicit_esp_port = os.getenv("ESP_SERIAL_PORT", "")
        explicit_lidar_port = os.getenv("LIDAR_SERIAL_PORT") or os.getenv("PI_LIDAR_PORT") or ""
        detected_serial_ports = list_serial_ports()
        lidar_fallback_port = "/dev/ttyUSB1" if motor_driver == MOTOR_DRIVER_ESP else "/dev/ttyUSB0"

        if lidar_enabled and not explicit_lidar_port and not explicit_esp_port and len(detected_serial_ports) == 1:
            lidar_port = detected_serial_ports[0].stable_device
        elif lidar_enabled:
            lidar_port = choose_serial_port(
                role="lidar",
                explicit_port=explicit_lidar_port,
                fallback_port=lidar_fallback_port,
                avoid_port=explicit_esp_port,
            )
        else:
            lidar_port = explicit_lidar_port or lidar_fallback_port

        esp_serial_port = choose_serial_port(
            role="esp",
            explicit_port=explicit_esp_port,
            fallback_port="/dev/ttyUSB0",
            avoid_port=lidar_port if lidar_enabled else "",
            allow_fallback=not (lidar_enabled and bool(lidar_port) and not explicit_esp_port),
        )

        if (
            lidar_enabled
            and esp_serial_port
            and lidar_port
            and same_serial_device(esp_serial_port, lidar_port)
            and not explicit_esp_port
        ):
            esp_serial_port = ""
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

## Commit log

2026-02-25 Create camera-overlay web app with controls and LiDAR placeholder
2026-02-25 Refine overlay controls, map placement, and switch icon
2026-02-25 Adjust LiDAR map size, color, and top-right placement
2026-02-25 Add larger secondary feed panel and corner camera switch
2026-02-25 Increase mini camera size and improve slide-toggle visibility
2026-02-25 Show full background camera frame without cropping
2026-02-25 Revert "Show full background camera frame without cropping"
    This reverts commit 8d9f29223a515d497387032c09c7551a9bab56c7.
2026-02-25 Add settings menu with full camera view toggle
2026-02-25 Set up Pi+ESP base stack for motor and camera gateway
2026-02-27 Motor test script using LEDs instead of motors
2026-02-27 Updated motor-safety behavior
2026-02-27 LiDAR testing added
2026-03-03 Backend input wiring
2026-03-04 Stream LiDAR data to web UI and remove Python-side visualization
2026-03-24 Add Pi motor echo mode
2026-03-25 Show Pi connection and temperature
2026-03-27 Reset LiDAR files.
2026-03-27 Wire LiDAR data into existing Pi web path
2026-03-27 Add LiDAR zoom controls to web radar
2026-03-27 Add LiDAR mode and improve radar rendering
2026-03-27 Enlarge camera previews in LiDAR mode
2026-03-27 Increase LiDAR mode camera layout size
2026-03-30 Harden Pi LiDAR streaming and venv startup
2026-03-30 Refine LiDAR frontend animation
2026-04-01 Stream dual Pi camera feeds to the frontend
2026-04-01 Add frontend camera FPS control
2026-04-01 Document the current robot stack
2026-04-01 Rename robot camera feeds to front and back
2026-04-02 Add Pi ESC motor controller scaffolding
2026-04-02 Add safe Pi ESC web control
2026-04-02 Expand LiDAR view camera feeds
2026-04-02 Keep recording pause button in sync
2026-04-03 Fix recorder pause and resume state flow
2026-04-03 Tighten recorder pause button responsiveness
2026-04-10 Sync lidar and drive controls with camera view
2026-04-10 Add direct Pi ESC setup guide
2026-04-10 Hide lidar overlay status text
2026-04-13 Add second WebRTC camera feed (#9)
2026-04-14 Restore WebRTC recovery and gate second camera
    Close stale Pi WebRTC peers on signaling reconnect, add browser offer retry, default the publisher back to front-only, and refresh Pi media sources so stale camera tracks do not survive disconnects.
2026-04-14 Prevent duplicate WebRTC offer restarts
    [webrtc_publisher.py]
2026-04-14 Adapt WebRTC camera profiles by view
2026-04-14 Keep WebRTC stable on camera flip
2026-04-14 Swap WebRTC output profiles without restart
    [webrtc_publisher.py]
2026-04-14 Switch Pi ESC control to lgpio
2026-04-14 Default ESC arming to low throttle
2026-04-14 Smooth ESC drive keepalive
2026-04-14 Refresh ESC pulses while holding drive
2026-04-14 Scale ESC throttle by requested speed
2026-04-14 Latch ESC drive pulses until stop
2026-04-15 Move ESC control onto ESP32 firmware
2026-04-15 Route motor control through ESP serial
2026-04-15 Document ESP32 serial ESC setup
2026-04-15 Throttle ESP motor status publishes
2026-04-20 Added chasis stl file
    [ProjectBasicFinal.stl]
2026-04-23 Configure ESP32 for bidirectional ESCs
2026-04-23 Fix ESP32 web motor control path
    [arrow_serial_bridge.py, main.cpp, serial_motor_test.py]
2026-04-23 Fix Pi ESP serial message buffering
    [gateway.py]
2026-04-28 Fix lidar serial routing diagnostics
    [gateway.py, lidar_check.py, serial_devices.py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]
2026-04-28 Prioritize lidar serial device
2026-04-28 Improve dual camera startup diagnostics
2026-04-28 Flip Pi camera feeds upright
    [gateway.py, webrtc_camera.py]
